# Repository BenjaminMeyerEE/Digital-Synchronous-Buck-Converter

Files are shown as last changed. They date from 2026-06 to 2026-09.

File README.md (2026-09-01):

# Digital Synchronous Buck Converter

12 V to 6 V, 10 A synchronous buck converter with closed-loop digital control on an
STM32G474RET6. Custom 4-layer board in KiCad. The firmware runs a 400 kHz PI voltage
loop with hardware-enforced dead-time and a comparator overcurrent trip that doesn't
depend on the CPU.

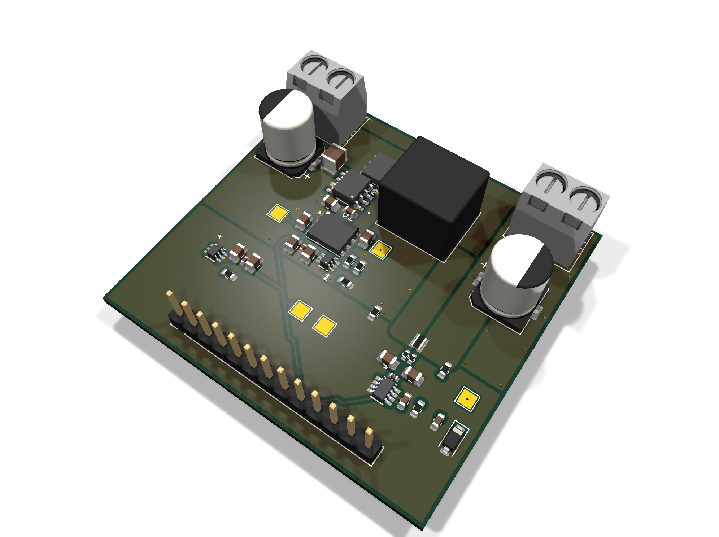
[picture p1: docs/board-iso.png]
Assembled board render


<!-- TODO
     - scope captures: switching node, gate drive dead-time, load step
     - characterization numbers, then update Status
     - write up why the F.Cu pour and In2.Cu are shaped the way they are
     images are all generated, see docs/regenerate-images.md
-->

## Specifications

| Parameter | Value |
|---|---|
| Input / output | 12 V → 6 V, 10 A |
| Board | 53.1 × 50.0 mm, 4-layer |
| Controller | STM32G474RET6 (Nucleo-G474RE) |
| Switching frequency | 400 kHz (TIM1 at 170 MHz, ARR = 424) |
| Control loop | Voltage-mode PI, one update per switching period (2.5 µs) |
| Dead-time | 100 ns, hardware-enforced (TIM1 DTG = 17) |
| Current sense | INA241A3, 50 V/V into a 5 mΩ shunt, so 0.25 V/A |
| Feedback divider | 0.4047619 (ADC sees V_out × gain) |
| Sampling | Dual-simultaneous 12-bit ADC, TIM1 TRGO triggered, DMA |
| Overcurrent protection | TLV3603 comparator into TIM1 BKIN2 |
| Gate driver | UCC27211D half-bridge |

## Status

The power stage works. I've driven it from a function generator and from the test
firmware in `test-firmware/`.

Still open: the main control firmware in `firmware/` hasn't run on hardware yet, so
the closed loop is unproven. The board also hasn't been characterized, so there are
no efficiency, regulation, ripple or thermal numbers. Both are waiting on lab
access, which was shut through August 2026.

## Repository layout

| Path | Contents |
|---|---|
| `hardware/` | KiCad 10 project: schematic, PCB, design rules, library tables |
| `firmware/` | Main control firmware (CubeMX + EWARM) |
| `test-firmware/` | Standalone open-loop PWM bring-up project |
| `fabrication/` | Gerbers, BOM, pick-and-place, interactive BOM |

## Hardware

4-layer stackup with a solid internal ground plane. All four copper layers are
plotted from the top and unmirrored so they line up with each other.

| `F.Cu` — top signal + power | `In1.Cu` — ground plane |
|---|---|
| F.Cu | In1.Cu |

| `In2.Cu` — power / signal | `B.Cu` — bottom signal + ground |
|---|---|
| In2.Cu | B.Cu |

`B.Cu` is meant to stay as close to unbroken ground as I could keep it. It only
carries routing where a connection couldn't be finished on another layer.

Schematic: [docs/schematic.pdf](docs/schematic.pdf). Top-down render:
[docs/board-top.png](docs/board-top.png).

27 BOM lines across 49 placements. Everything in `fabrication/` comes out of the
KiCad fabrication toolkit: gerbers, a JLCPCB-format BOM and centroid file, and an
interactive HTML BOM at `fabrication/bom/ibom.html`.

## Firmware

### Control

`Buck_CtrlLoopISR()` runs at 400 kHz. It's called from a lean direct-register DMA
handler rather than going through HAL dispatch, which keeps it inside the 2.5 µs
budget. V_FB and current sense are sampled at the same instant by the dual ADC and
come back as a single 32-bit DMA word.

PI with anti-windup. Integrator and duty are both clamped to `[0, duty_limit]`, and
the clamps reject NaN so a bad value written at runtime can't reach the duty cycle.
Analog scaling uses precomputed reciprocals to keep division out of the ISR.

Gains, setpoints and the overcurrent trip level are tunable at runtime over SWD with
STM32CubeMonitor. Monitoring variables are read-only.

### Protection

Overcurrent shutdown is pure hardware: the TLV3603 comparator drives TIM1 BKIN2
directly and kills the gates in under 100 ns. It still works with the CPU halted or
hung. The software break callback only does bookkeeping, forcing MOE off, masking
the break IRQ so it can't storm, and latching the fault.

IWDG is set to 2 s, and the main loop only refreshes it while the control ISR
heartbeat is advancing. A stalled ADC or DMA path resets the board to idle instead
of leaving the half-bridge running open-loop.

TIM3 dual-edge input capture timestamps the gate edges in hardware, so the
dead-time at the power stage is measured rather than assumed.

## Test firmware

`test-firmware/` is a separate project for bringing the power stage up before
closing the loop. Open-loop complementary PWM at 400 kHz with the same 100 ns
hardware dead-time. It holds everything off for 500 ms after reset so the rails
settle and the debugger can attach, then soft-starts by walking CCR up 4 counts
every 2 ms, roughly 106 ms from 0 to 50 % duty. Kept separate so the gate drive can
be checked on its own.

## Toolchain

The CubeMX project targets EWARM V8.50. It also builds clean under
`arm-none-eabi-gcc` 14.3 (the one bundled with STM32CubeIDE 2.1.1) at
`-O2 -Wall -Wextra` with no warnings, using about 64 KB of flash and 2.4 KB of RAM.

Flash over ST-Link with STM32CubeProgrammer. CubeMonitor needs the exact `.out` ELF
matching what's on the chip, otherwise the symbol addresses won't line up.

TIM1 and IWDG are both frozen on core halt via DBGMCU, so halting in the debugger is
safe. A halt does leave the gates frozen wherever they were. The BKIN2 kill still
works while halted, but don't halt under load with the OC comparator disarmed.

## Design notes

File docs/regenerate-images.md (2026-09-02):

# Regenerating the images

Everything in `docs/` is generated from the design files with `kicad-cli`, so the
images can be rebuilt after any board change rather than re-screenshotted.

On Windows the binary is at:

    "C:/Program Files/KiCad/10.0/bin/kicad-cli.exe"

Run all commands from the repository root.

## 3D renders

Isometric view (README header):

    kicad-cli pcb render -o docs/board-iso.png --quality high --perspective \
      --rotate '-30,0,-35' --zoom 0.7 --width 2000 --height 1500 \
      --background transparent hardware/synch_buck_digital.kicad_pcb

Top-down view:

    kicad-cli pcb render -o docs/board-top.png --side top --quality high \
      --width 2000 --height 1500 --background transparent \
      hardware/synch_buck_digital.kicad_pcb

Transparent backgrounds are deliberate — they read correctly on both GitHub's
light and dark themes.

## Copper layers

One SVG per copper layer, each with the board outline for reference:

    for pair in "F.Cu:layer-f-cu" "In1.Cu:layer-in1-cu" \
                "In2.Cu:layer-in2-cu" "B.Cu:layer-b-cu"; do
      L="${pair%%:*}"; N="${pair##*:}"
      kicad-cli pcb export svg -o "docs/$N.svg" --mode-single \
        --layers "$L,Edge.Cuts" --exclude-drawing-sheet --page-size-mode 2 \
        --check-zones hardware/synch_buck_digital.kicad_pcb
    done

Then darken the board outline, because KiCad plots `Edge.Cuts` as `#D0D2CD`,
which disappears against a white page:

    sed -i 's/#D0D2CD/#555555/g' docs/layer-*.svg

Two deliberate choices:

- **Silkscreen is excluded.** KiCad plots it as `#F2EDA1`, effectively invisible
  on GitHub's light background.
- **`B.Cu` is not mirrored.** Plotting every layer from the same side means
  features line up when comparing layers, which is the point of showing them.

## Schematic

    kicad-cli sch export pdf -o docs/schematic.pdf \
      hardware/synch_buck_digital.kicad_sch

## Notes

- `--check-zones` refills copper pours before plotting, so layer images always
  reflect the current zone settings.
- Close the KiCad PCB editor before regenerating. `kicad-cli` reads from disk,
  and an open editor can overwrite the board file when it saves.

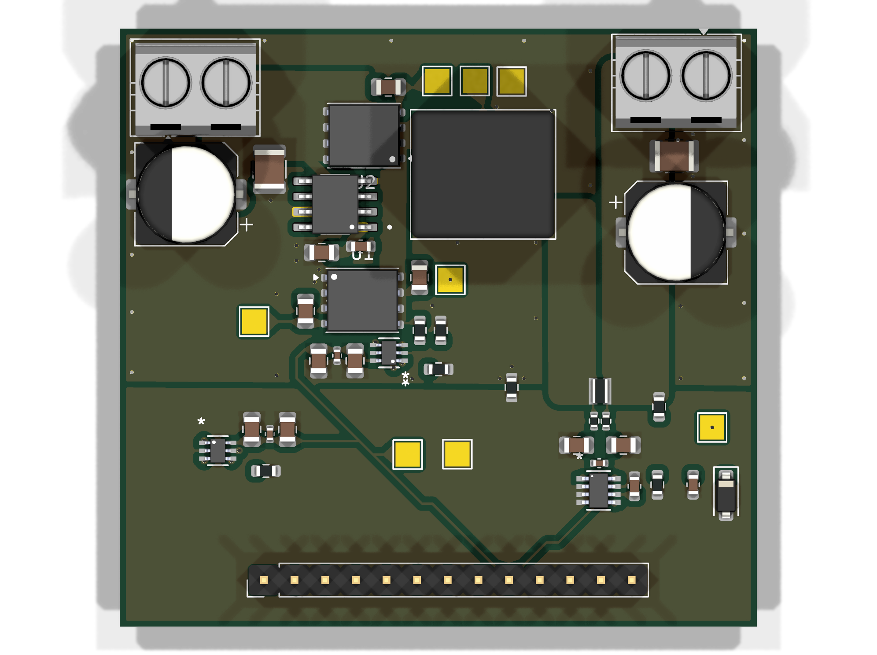
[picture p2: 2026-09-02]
docs/board-top.png

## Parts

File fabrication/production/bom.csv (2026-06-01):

Designator | Footprint | Quantity | Value | LCSC Part #
CB1 | 0805 | 1 | 47nF
C_DT_100P1, C_INA_FILT2, C_INA_FILT3, C_OC_100P1 | 0805 | 4 | 100pF
C_DT_10N1, C_OC_10N1 | 0402 | 2 | 10nF
C_DT_1U1, C_OC_1U1, C_UCC_VDD_HF1 | 0805 | 3 | 1uF
C_INA_FILT1 | 0402 | 1 | 1nF
C_INA_VCC1, C_UCC_VDD_LF1 | 0603 | 2 | 100nF
C_IN_HF1, C_OUT_HF1 | 1210 | 2 | 10uF
C_IN_LF1, C_OUT_LF1 | CP_Elec_8x10 | 2 | 47uF
C_VFB_FILT1 | 0603 | 1 | 1nF
D1 | D_SOD-123 | 1 | 3.3V
J_IN1, J_OUT1 | TerminalBlock_MaiXu_MX126-5.0-02P_1x02_P5.00mm | 2 | Conn_01x02
J_STM1 | PinHeader_1x13_P2.54mm_Vertical | 1 | Conn_01x13
L1 | L_Coilcraft_XAL1010-XXX | 1 | 6.8uH
R1 | 0603 | 1 | 0R
R1_DT1 | 0603 | 1 | 3.9KR
R1_VFB1 | 0603 | 1 | 6.8KR
R2_DT1 | 0603 | 1 | 1KR
R2_VFB1 | 0603 | 1 | 10KR
R_FILT_N1, R_FILT_P1 | 0402 | 2 | 10R
R_GATE_1, R_GATE_2 | 0805 | 2 | 10R
R_HYS1, R_HYS2 | 0603 | 2 | 75KR
R_SHUNT1 | RES_2012_SUS | 1 | 5mR
TP1, TP2, TP3, TP4, TP5, TP6, TP7, TP8 | TestPoint_Pad_2.0x2.0mm | 8 | TestPoint
U1, U2 | Infineon_PG-TDSON-8_6.15x5.15mm | 2 | BSC066N06NSATMA1
U3 | SOT23-8_DDF_TEX | 1 | INA241A3IDDFR
U_DT1, U_OC1 | SC70_DCK_TEX | 2 | TLV3603DCKR-ET
U_UCC1 | SOIC127P599X175-8N | 1 | UCC27211D

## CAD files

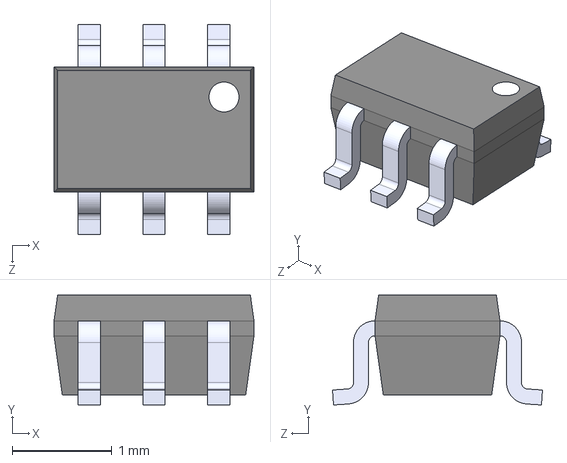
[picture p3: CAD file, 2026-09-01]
hardware/3dmodels/TLV3603DCKR.step
2.00 x 1.10 x 2.10 mm

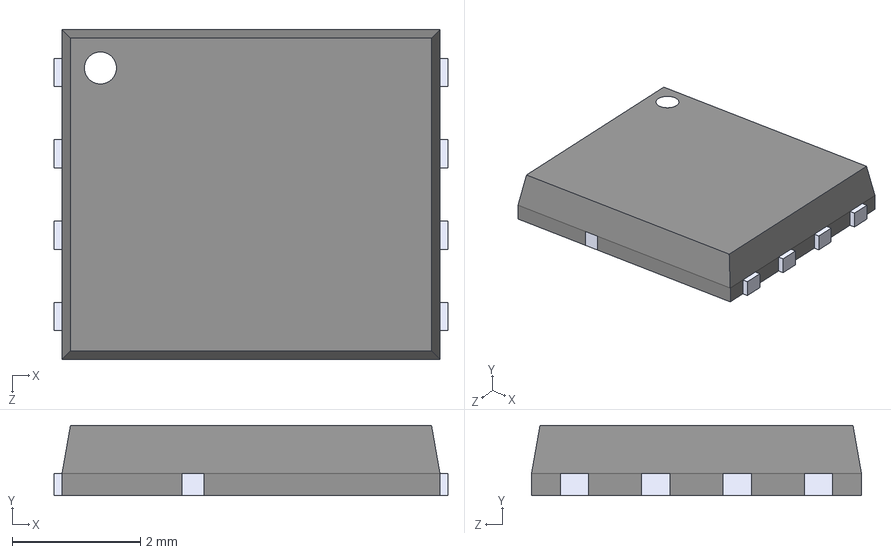
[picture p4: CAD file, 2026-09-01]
hardware/3dmodels/Infineon_PG-TDSON-8.step
6.15 x 1.10 x 5.15 mm

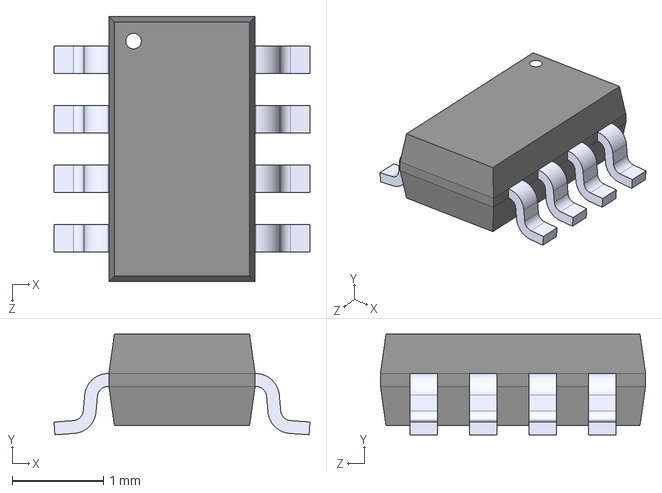
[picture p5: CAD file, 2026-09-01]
hardware/3dmodels/INA241A3IDDFR.step
2.80 x 1.10 x 2.90 mm

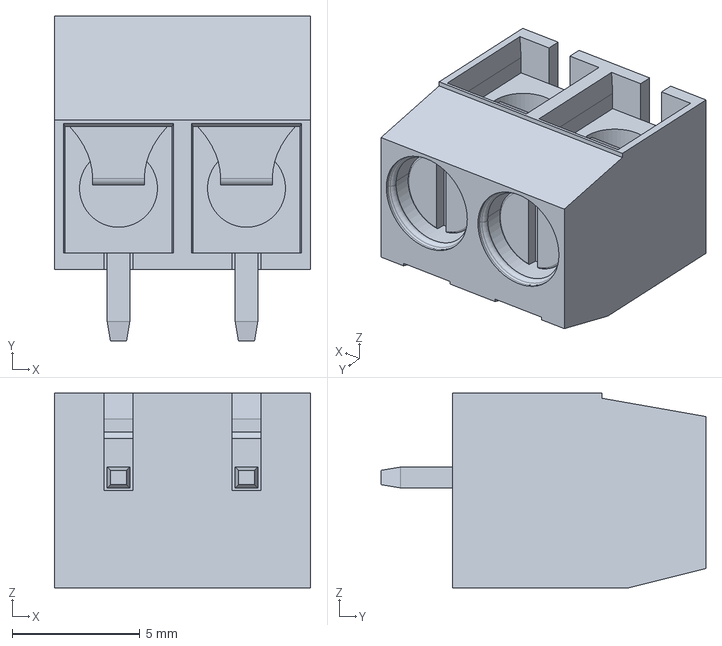
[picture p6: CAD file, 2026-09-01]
hardware/3dmodels/TerminalBlock_MX126-5.0-02P.step
10.0 x 12.7 x 7.62 mm

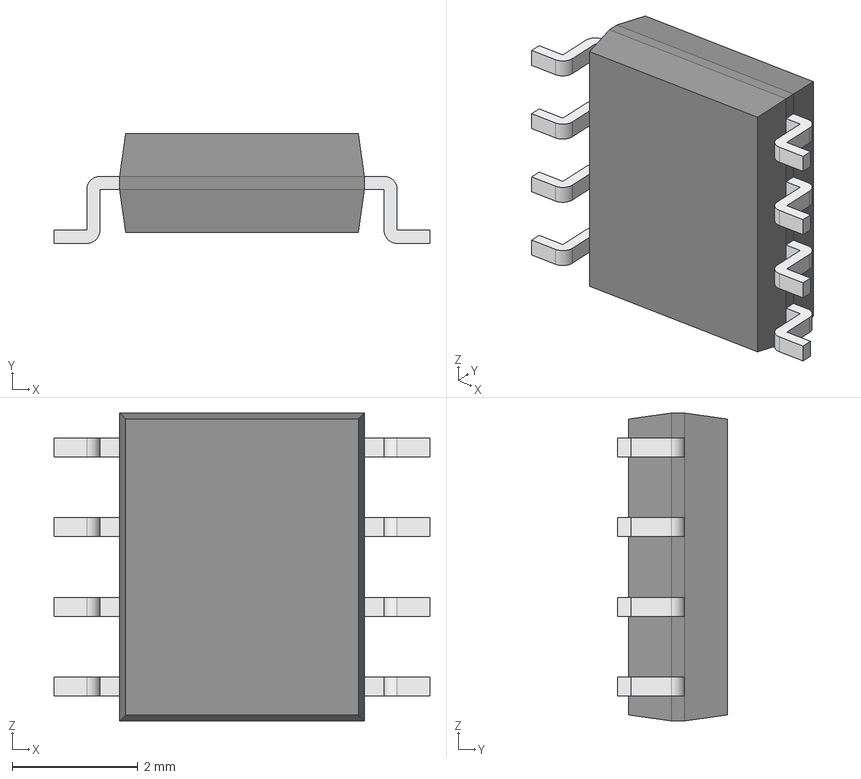
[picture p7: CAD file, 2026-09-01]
hardware/3dmodels/UCC27211D.step
5.99 x 1.75 x 4.91 mm
Body001 (Mirror #1) x 4
XY-plane x 12
X-axis x 12

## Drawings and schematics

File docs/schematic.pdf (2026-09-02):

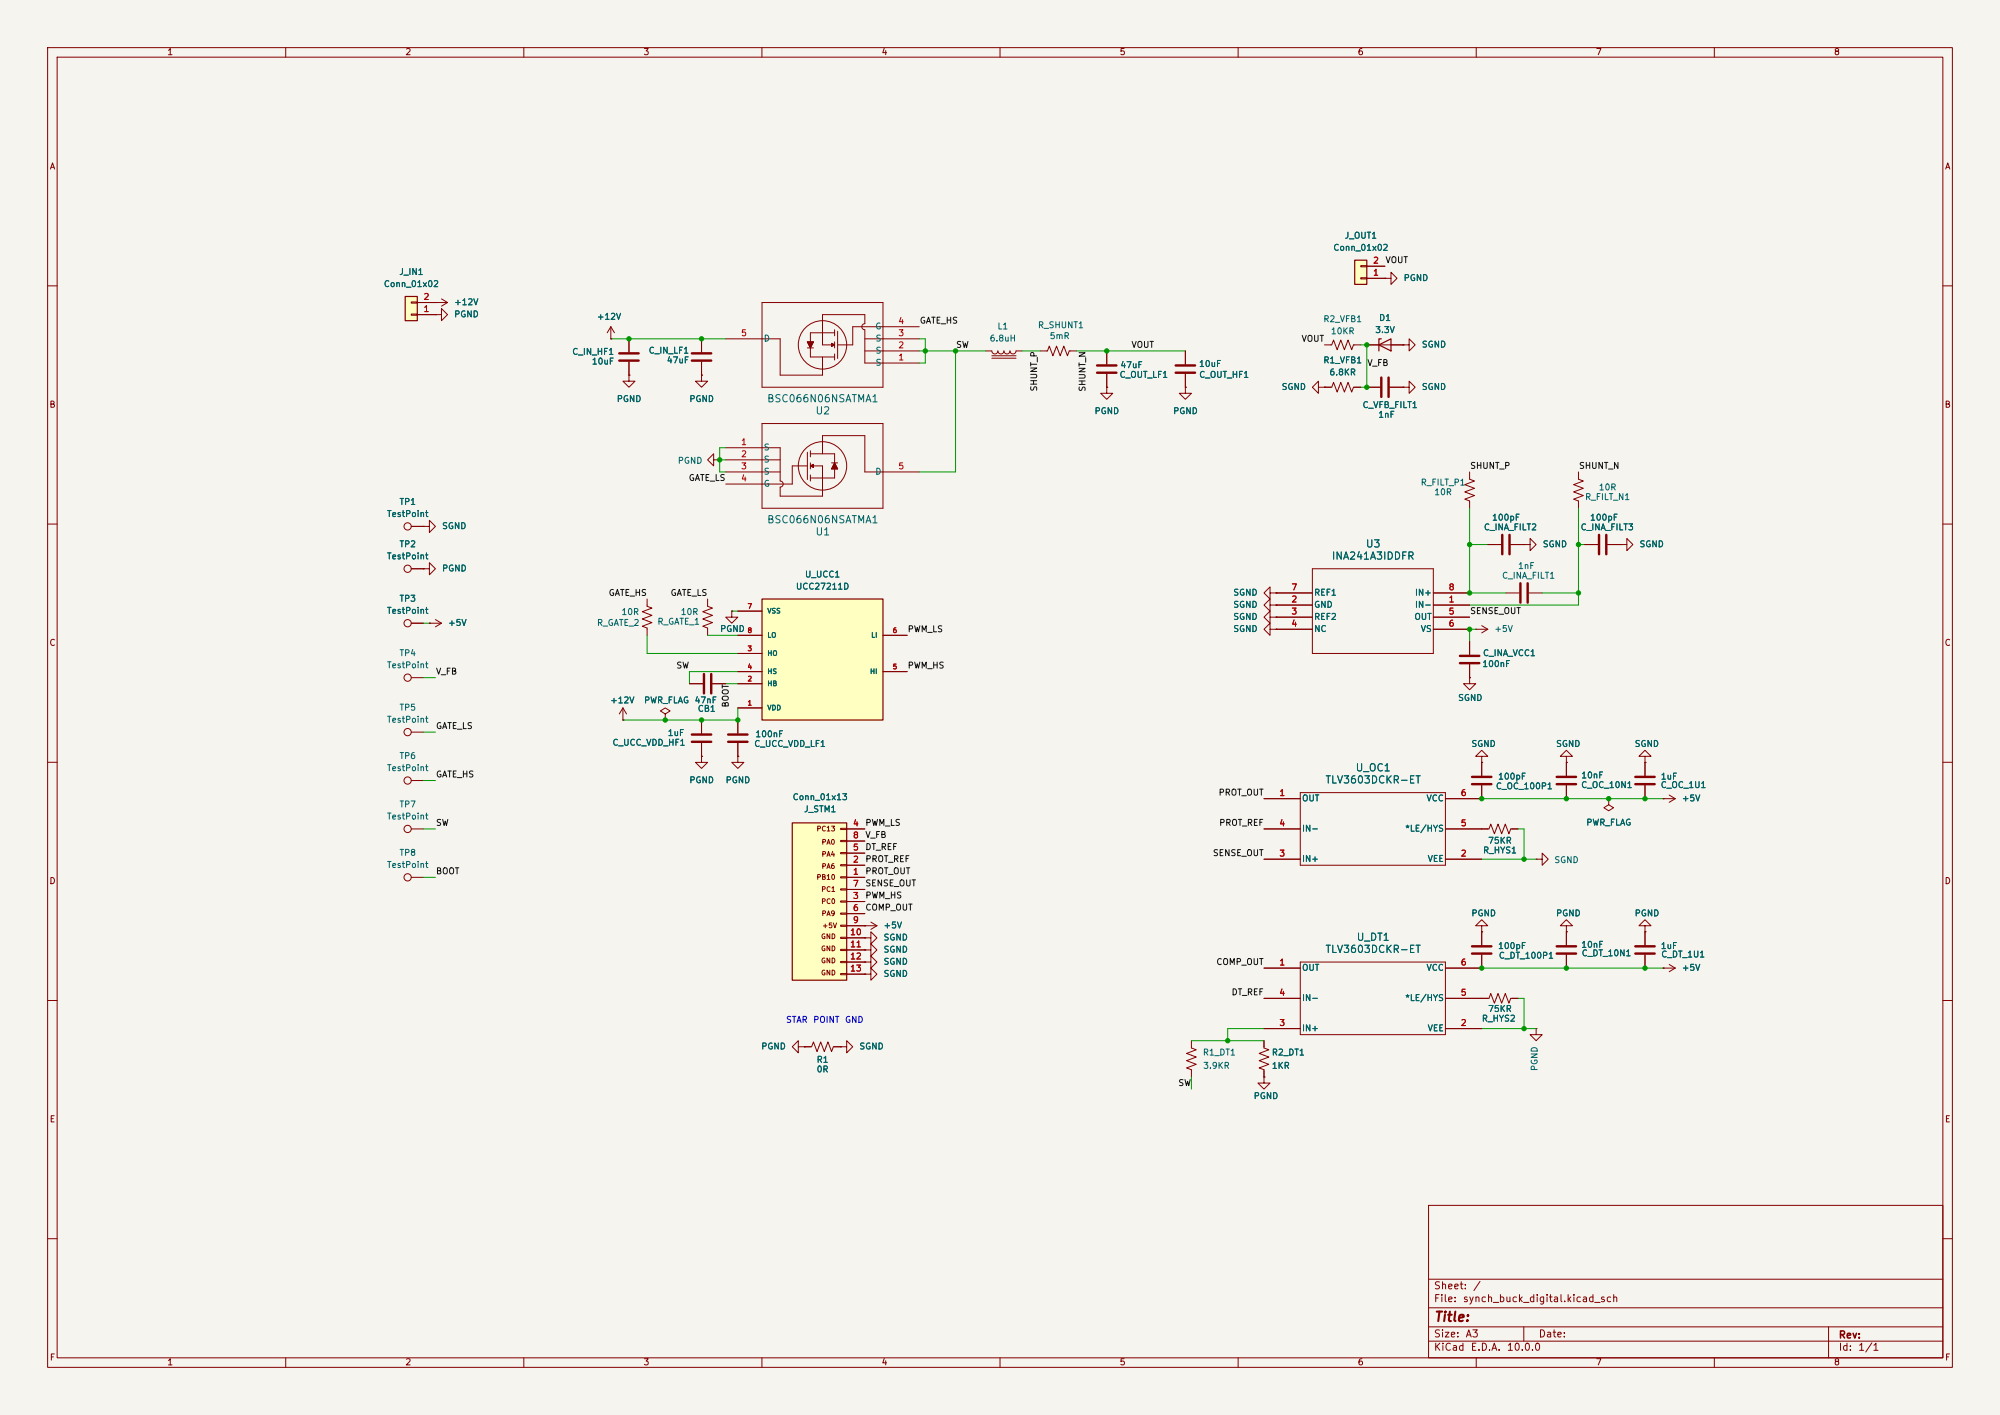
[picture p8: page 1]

Size: A3 | Rev: | F Date:
KiCad E.D.A. 10.0.0 | Id: 1/1

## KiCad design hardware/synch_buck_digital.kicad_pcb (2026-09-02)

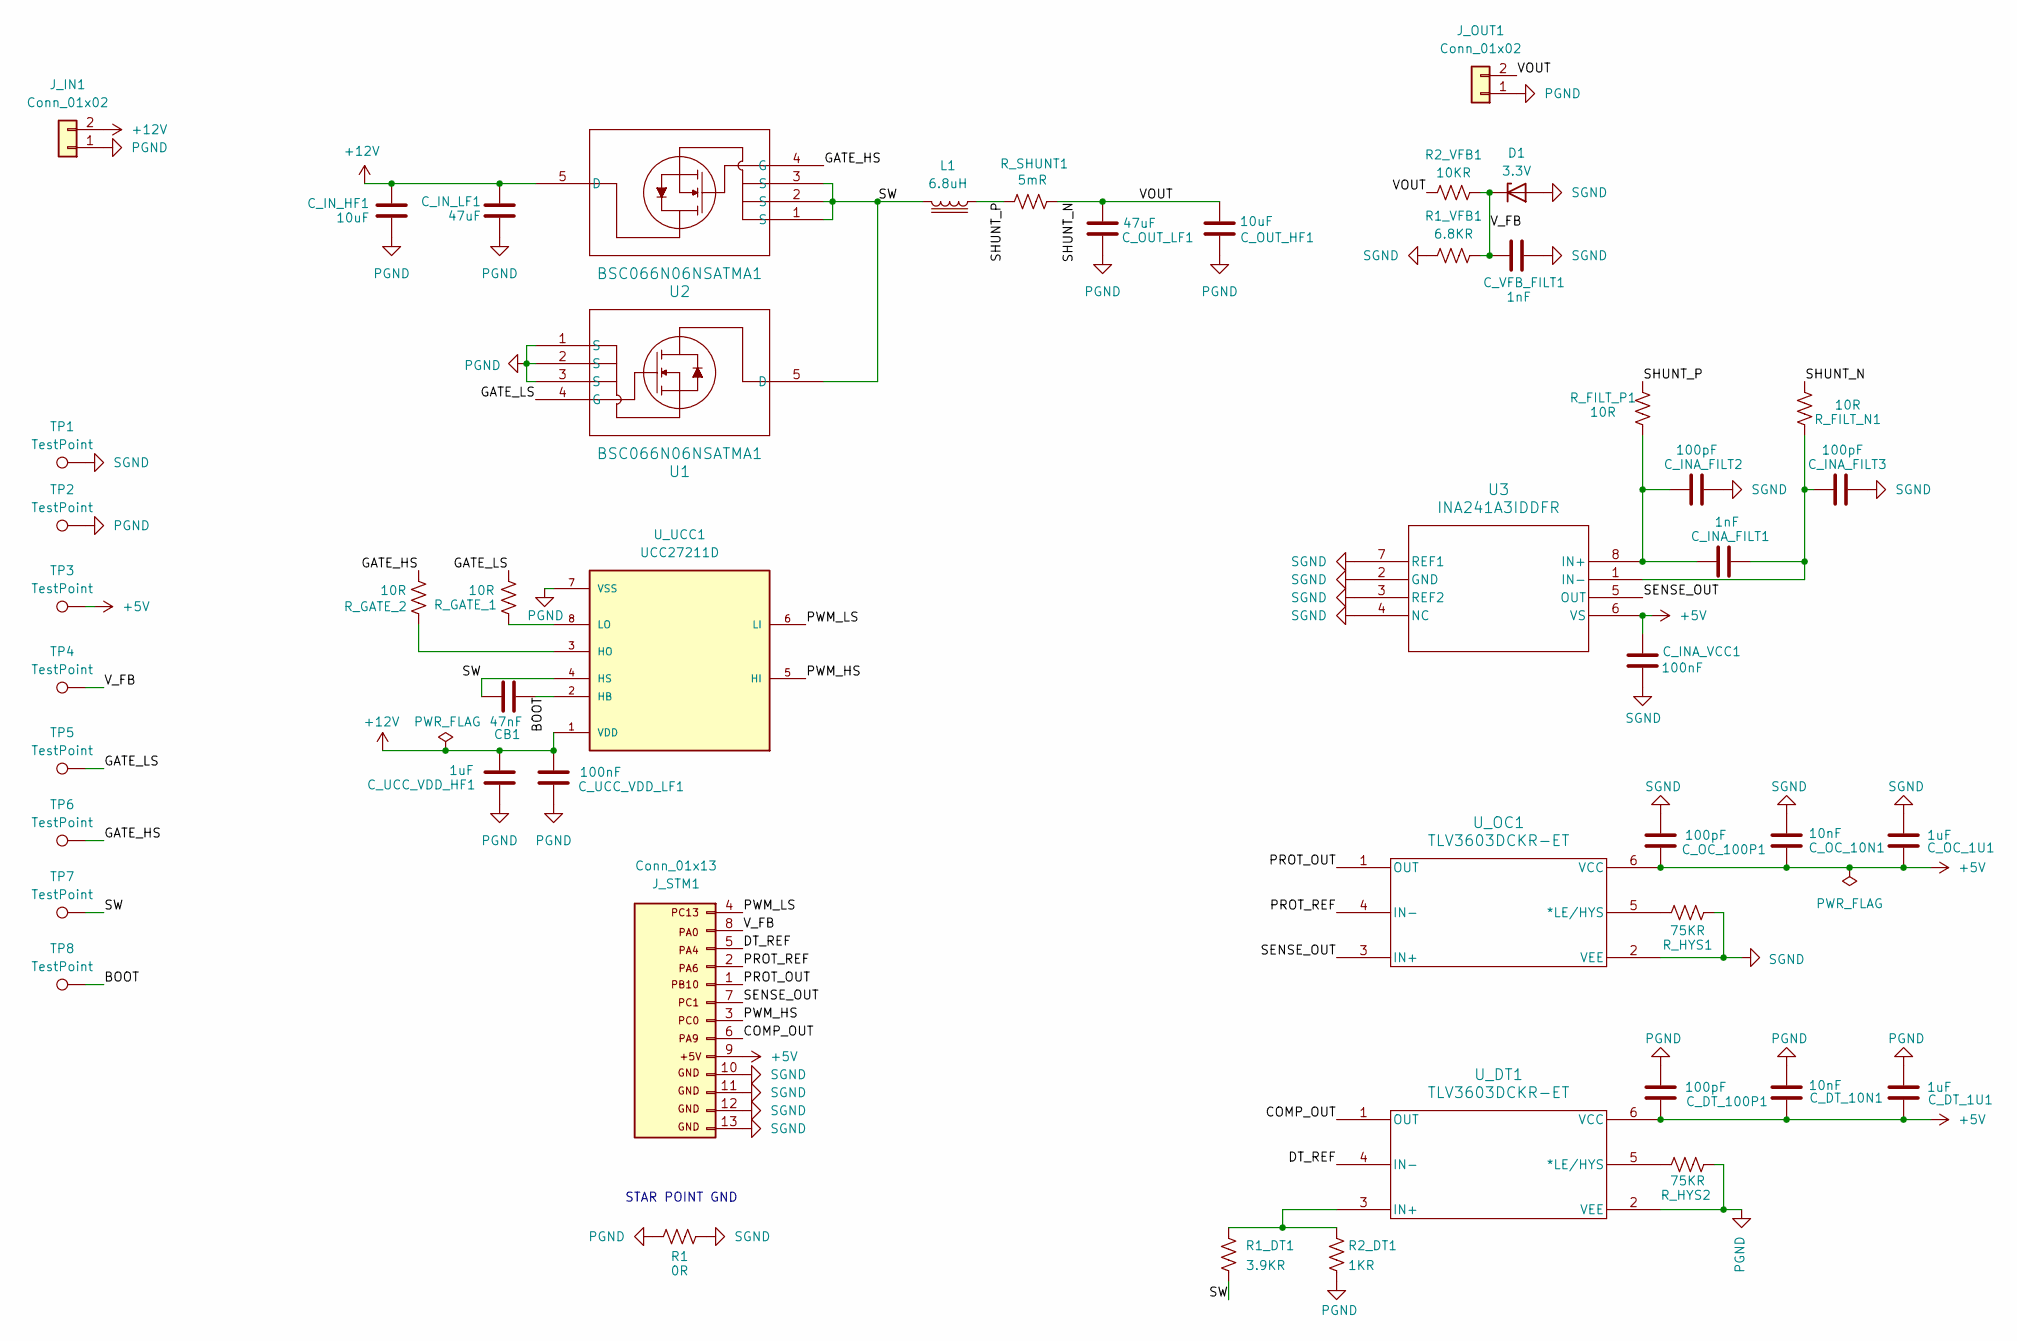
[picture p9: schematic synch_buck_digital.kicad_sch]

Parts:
CB1: 47nF; C_0805_2012Metric
C_DT_1U1: 1uF; C_0805_2012Metric
C_DT_10N1: 10nF; C_0402_1005Metric
C_DT_100P1: 100pF; C_0805_2012Metric
C_INA_FILT1: 1nF; C_0402_1005Metric
C_INA_FILT2, C_INA_FILT3: 100pF; C_0805_2012Metric
C_INA_VCC1: 100nF; C_0603_1608Metric
C_IN_HF1: 10uF; C_1210_3225Metric
C_IN_LF1: 47uF; CP_Elec_8x10
C_OC_1U1: 1uF; C_0805_2012Metric
C_OC_10N1: 10nF; C_0402_1005Metric
C_OC_100P1: 100pF; C_0805_2012Metric
C_OUT_HF1: 10uF; C_1210_3225Metric
C_OUT_LF1: 47uF; CP_Elec_8x10
C_UCC_VDD_HF1: 1uF; C_0805_2012Metric
C_UCC_VDD_LF1: 100nF; C_0603_1608Metric
C_VFB_FILT1: 1nF; C_0603_1608Metric
D1: 3.3V; D_SOD-123
J_IN1: Conn_01x02; TerminalBlock_MaiXu_MX126-5.0-02P_1x02_P5.00mm
J_OUT1: Conn_01x02; TerminalBlock_MaiXu_MX126-5.0-02P_1x02_P5.00mm
J_STM1: Conn_01x13; PinHeader_1x13_P2.54mm_Vertical
L1: 6.8uH; L_Coilcraft_XAL1010-XXX
R1: 0R
R1_DT1: 3.9KR; R_0603_1608Metric
R1_VFB1: 6.8KR; R_0603_1608Metric
R2_DT1: 1KR; R_0603_1608Metric
R2_VFB1: 10KR; R_0603_1608Metric
R_FILT_N1: 10R; R_0402_1005Metric
R_FILT_P1: 10R; R_0402_1005Metric
R_GATE_1, R_GATE_2: 10R; C_0805_2012Metric
R_HYS1, R_HYS2: 75KR; R_0603_1608Metric
R_SHUNT1: 5mR; RES_2012_SUS
TP1, TP2, TP3, TP4, TP5, TP6, TP7, TP8: TestPoint; TestPoint_Pad_2.0x2.0mm
U1, U2: BSC066N06NSATMA1; Infineon_PG-TDSON-8_6.15x5.15mm
U3: INA241A3IDDFR; SOT23-8_DDF_TEX
U_DT1: TLV3603DCKR-ET; SC70_DCK_TEX
U_OC1: TLV3603DCKR-ET; SC70_DCK_TEX
U_UCC1: UCC27211D; SOIC127P599X175-8N; PARTREV F

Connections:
+5V: C_DT_1U1.1, C_DT_10N1.1, C_DT_100P1.1, C_INA_VCC1.1, C_OC_1U1.1, C_OC_10N1.1, C_OC_100P1.1, J_STM1.9, TP3.1 (1_1), U3.6 (VS), U_DT1.6 (VCC), U_OC1.6 (VCC)
+12V: C_IN_HF1.1, C_IN_LF1.1, C_UCC_VDD_HF1.2, C_UCC_VDD_LF1.2, J_IN1.2, U2.5 (D), U_UCC1.1 (VDD)
/BOOT: CB1.1, TP8.1 (1_1), U_UCC1.2 (HB)
/COMP_OUT: J_STM1.6 (Pin_8), U_DT1.1 (OUT)
/DT_REF: J_STM1.5 (Pin_3), U_DT1.4 (IN-)
/GATE_HS: R_GATE_2.1, TP6.1 (1_1), U2.4 (G)
/GATE_LS: R_GATE_1.2, TP5.1 (1_1), U1.4 (G)
/PROT_OUT: J_STM1.1 (Pin_5), U_OC1.1 (OUT)
/PROT_REF: J_STM1.2 (Pin_4), U_OC1.4 (IN-)
/PWM_HS: J_STM1.3 (Pin_7), U_UCC1.5 (HI)
/PWM_LS: J_STM1.4 (Pin_1), U_UCC1.6 (LI)
/SENSE_OUT: J_STM1.7 (Pin_6), U3.5 (OUT), U_OC1.3 (IN+)
/SHUNT_N: C_OUT_HF1.1, C_OUT_LF1.1, J_OUT1.2, R2_VFB1.1, R_FILT_N1.2, R_SHUNT1.2
/SHUNT_P: L1.1, R_FILT_P1.1, R_SHUNT1.1
/SW: CB1.2, L1.2, R1_DT1.2, TP7.1 (1_1), U1.5 (D), U2.1 (S), U2.2 (S), U2.3 (S), U_UCC1.4 (HS)
/V_FB: C_VFB_FILT1.2, D1.1 (K), J_STM1.8 (Pin_2), R1_VFB1.2, R2_VFB1.2, TP4.1 (1_1)
unnamed: C_INA_FILT1.2, C_INA_FILT2.2, R_FILT_P1.2, U3.8 (IN+)
unnamed: C_INA_FILT1.1, C_INA_FILT3.2, R_FILT_N1.1, U3.1 (IN-)
unnamed: R_HYS2.2, U_DT1.5 (*LE/HYS)
unnamed: R1_DT1.1, R2_DT1.2, U_DT1.3 (IN+)
unnamed: R_HYS1.2, U_OC1.5 (*LE/HYS)
unnamed: R_GATE_2.2, U_UCC1.3 (HO)
unnamed: R_GATE_1.1, U_UCC1.8 (LO)
PGND: C_DT_1U1.2, C_DT_10N1.2, C_DT_100P1.2, C_IN_HF1.2, C_IN_LF1.2, C_OUT_HF1.2, C_OUT_LF1.2, C_UCC_VDD_HF1.1, C_UCC_VDD_LF1.1, J_IN1.1, J_OUT1.1, R1.1, R2_DT1.1, R_HYS2.1, TP2.1 (1_1), U1.1 (S), U1.2 (S), U1.3 (S), U_DT1.2 (VEE), U_UCC1.7 (VSS)
SGND: C_INA_FILT2.1, C_INA_FILT3.1, C_INA_VCC1.2, C_OC_1U1.2, C_OC_10N1.2, C_OC_100P1.2, C_VFB_FILT1.1, D1.2 (A), J_STM1.10, J_STM1.11, J_STM1.12, J_STM1.13, R1.2, R1_VFB1.1, R_HYS1.1, TP1.1 (1_1), U3.2 (GND), U3.3 (REF2), U3.4 (NC), U3.7 (REF1), U_OC1.2 (VEE)

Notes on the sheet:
STAR POINT GND

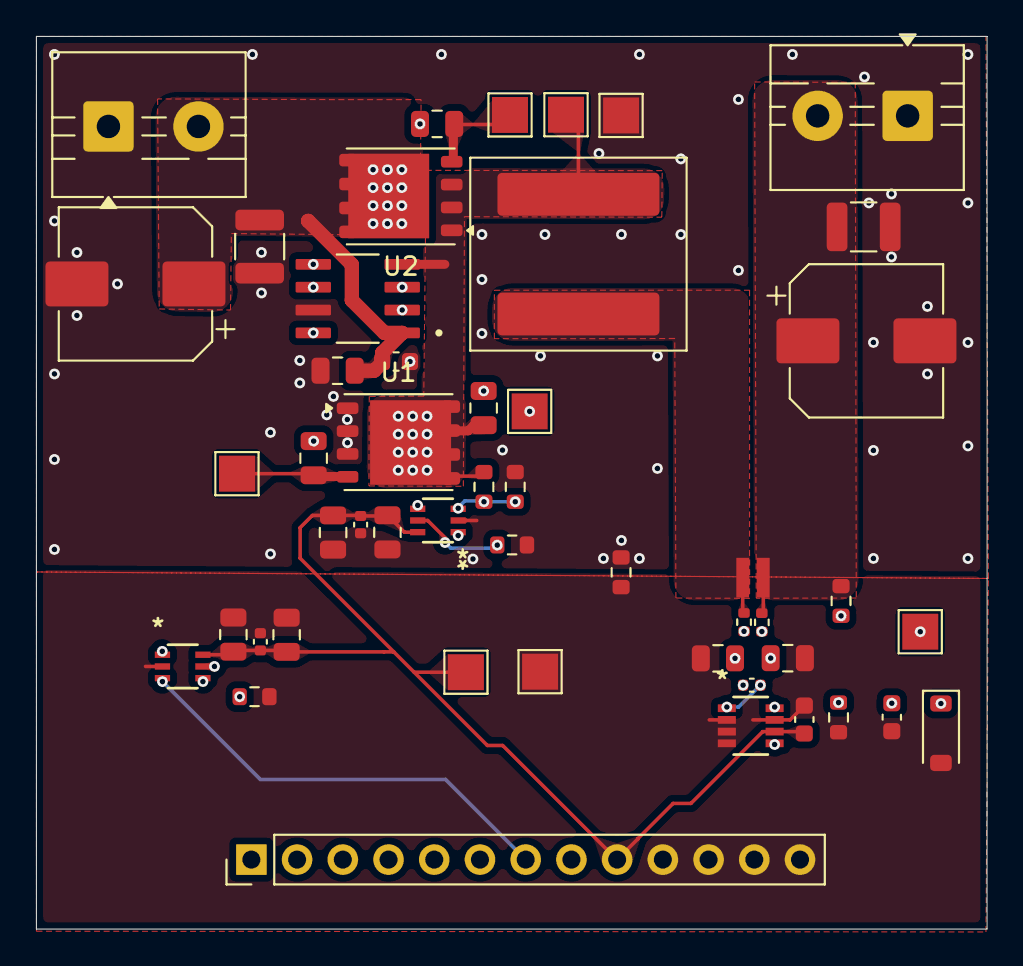
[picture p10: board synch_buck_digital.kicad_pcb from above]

Board: 4 copper layers, 52.8 x 49.6 mm, 49 parts (0 on the bottom side), 25 nets.

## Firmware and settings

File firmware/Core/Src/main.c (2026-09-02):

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
/* Includes ------------------------------------------------------------------*/
#include "main.h"

/* USER CODE BEGIN PTD */
/* sys_state_t moved to main.h (USER CODE ET): it is now shared with the lean
 * DMA error path in stm32g4xx_it.c, which latches SYS_STATE_FAULT directly. */
/* USER CODE END PTD */

/* USER CODE BEGIN PD */
/* --- Power stage / timing --------------------------------------------------
 * TIM1: 170 MHz, PSC = 0, ARR = 424 -> Fsw = 400 kHz, period = 2.5 us.
 * DTG = 17 -> hardware dead-time = 17 / 170 MHz = 100 ns per switching edge. */
#define PWM_PERIOD_TICKS        425.0f      /* ARR + 1                                    */
#define CTRL_TS_SEC             2.5e-6f     /* control ISR period (TIM1 update = 400 kHz) */
#define PWM_DEADTIME_NS         100.0f
#define PWM_PERIOD_NS           2500.0f
/* LS on-time loses one dead-time at each of its two transitions -> 8 % of period */
#define PWM_DEADTIME_PCT        (2.0f * PWM_DEADTIME_NS / PWM_PERIOD_NS * 100.0f)
#define CCR_TO_PCT              (100.0f / PWM_PERIOD_TICKS)

/* --- Analog scaling (precomputed reciprocals: no division in the ISR) ------ */
#define ADC_VREF_V              3.3f
#define ADC_FULL_SCALE          4095.0f
#define VFB_DIVIDER_GAIN        0.4047619f  /* V_FB divider: ADC sees Vout * this         */
#define CURR_SENSE_V_PER_A      0.25f       /* INA241A3 gain 50 x 5 mOhm shunt            */
#define ADC_RAW_TO_VOUT_V       ((ADC_VREF_V / ADC_FULL_SCALE) / VFB_DIVIDER_GAIN)   /* ~1.9910e-3 V/LSB */
#define ADC_RAW_TO_AMPS         ((ADC_VREF_V / ADC_FULL_SCALE) / CURR_SENSE_V_PER_A) /* ~3.2234e-3 A/LSB */
#define AMPS_TO_DAC_COUNTS      (CURR_SENSE_V_PER_A * ADC_FULL_SCALE / ADC_VREF_V)   /* ~310.23 LSB/A    */
#define DAC_FULL_SCALE_A        13.2f       /* 3.3 V / 0.25 V/A: max representable trip   */

/* --- Limits / interlocks ---------------------------------------------------- */
#define OC_TRIP_MIN_A           0.5f        /* start refused while set_oc_trip_A < this   */
#define DUTY_MAX_ABS            0.98f       /* absolute ceiling for set_duty_max          */
#define VOUT_SET_MAX_V          8.0f        /* V_FB divider saturates the ADC at ~8.15 V  */
#define SOFTSTART_MS_MIN        1.0f        /* also guards the ramp-increment division    */
#define SOFTSTART_MS_MAX        10000.0f

/* --- Start-up hold ----------------------------------------------------------
 * Nothing may be armed for this long after reset. Gives the input rail, the
 * INA241 sense amp and the TLV3603 OC comparator (whose PROT_REF is only
 * written once the main loop reaches app_apply_dac_refs()) time to settle, and
 * gives the debugger time to take hold before the half-bridge can ever be
 * energized. Enforced as a non-blocking gate on cmd_start rather than as a
 * HAL_Delay(): the main loop must keep servicing the IWDG heartbeat gate and
 * the CubeMonitor variables throughout the hold.                              */
#define STARTUP_HOLD_MS         500u

/* --- LD2 state indicator blink cadence (non-blocking) ----------------------- */
#define LED_BLINK_SOFTSTART_MS  100u        /* fast blink while ramping                  */
#define LED_BLINK_RUN_MS        500u        /* slow blink while regulating               */
/* USER CODE END PD */


COM_InitTypeDef BspCOMInit;
ADC_HandleTypeDef hadc1;
ADC_HandleTypeDef hadc2;
DMA_HandleTypeDef hdma_adc1;

DAC_HandleTypeDef hdac1;
DAC_HandleTypeDef hdac2;

IWDG_HandleTypeDef hiwdg;

TIM_HandleTypeDef htim1;
TIM_HandleTypeDef htim3;

/* USER CODE BEGIN PV */
/* ===================== CubeMonitor: monitoring (firmware -> user) ========= */
volatile float    mon_vout_V             = 0.0f;           /* measured output voltage [V]            */
volatile float    mon_current_A          = 0.0f;           /* measured output current [A]            */
volatile float    mon_pwm_hs_duty_pct    = 0.0f;           /* high-side effective duty [%]           */
volatile float    mon_pwm_ls_duty_pct    = 0.0f;           /* low-side effective duty [%]            */
volatile uint8_t  mon_pwm_hs_active      = 0u;             /* 1 = MOE on and HS switching            */
volatile uint8_t  mon_pwm_ls_active      = 0u;             /* 1 = MOE on (LS driven)                 */
volatile uint8_t  mon_prot_out_state     = 0u;             /* live PROT_OUT pin level (PA11)         */
volatile uint8_t  mon_dt_out_state       = 0u;             /* live DT_OUT comparator level (PB4)     */
volatile uint32_t mon_dt_edge_count      = 0u;             /* total DT_OUT edges captured by TIM3    */
volatile uint32_t mon_dt_pulse_width_ns  = 0u;             /* last DT_OUT high-pulse width [ns]      */
volatile uint8_t  mon_sys_state          = SYS_STATE_INIT; /* sys_state_t enum                       */
volatile uint8_t  mon_fault_latched      = 0u;             /* 1 = BRK2 fault latched                 */
volatile uint8_t  mon_interlock_oc_not_armed = 0u;         /* 1 = set_oc_trip_A < 0.5 A, start blocked */
volatile uint32_t mon_ctrl_loop_count    = 0u;             /* 400 kHz control ISR heartbeat          */

/* ===================== CubeMonitor: tunables (user -> firmware) =========== */
volatile float set_vout_V       = 6.0f;   /* output voltage setpoint [V], clamp [0, 8.0]             */
volatile float set_kp           = 0.02f;  /* PI proportional gain [duty/V], clamp >= 0               */
volatile float set_ki           = 50.0f;  /* PI integral gain [duty/(V*s)], clamp >= 0               */
volatile float set_oc_trip_A    = 0.0f;   /* OC comparator trip [A]; must be >= 0.5 A to allow start */
volatile float set_dt_ref_A     = 0.1f;   /* switching-activity comparator threshold [A]             */
volatile float set_duty_max     = 0.95f;  /* HS duty ceiling [0..1], clamp [0, 0.98]                 */
volatile float set_softstart_ms = 50.0f;  /* soft-start ramp duration [ms], clamp [1, 10000]         */

/* ===================== CubeMonitor: commands (write 1; consumed by main loop) */
volatile uint8_t cmd_start       = 0u;    /* request IDLE -> SOFT_START                              */
volatile uint8_t cmd_stop        = 0u;    /* request SOFT_START/RUN -> IDLE                          */
volatile uint8_t cmd_clear_fault = 0u;    /* request FAULT -> IDLE (only if PROT_OUT low)            */

/* ===================== internal control state ============================= */
static volatile uint32_t adc_dual_raw = 0u;       /* DMA dest: ADC1 (V_FB) low half, ADC2 (SENSE) high half */
static volatile float ctrl_integrator = 0.0f;     /* PI integrator [duty]                                   */
static volatile float ctrl_duty_limit = 0.0f;     /* soft-start ramped duty ceiling [duty]                  */
static volatile float ctrl_ss_increment = 0.0f;   /* duty-limit increment per control tick                  */
static volatile float ctrl_duty_max_cached = 0.0f;/* clamped copy of set_duty_max (main-loop owned)         */
static volatile uint8_t ctrl_ramp_done = 0u;      /* control ISR -> main loop: soft-start ramp finished     */
static float dac_oc_applied_A = -1.0f;            /* last value written to PROT_REF (-1 forces first write) */
static float dac_dt_applied_A = -1.0f;            /* last value written to DT_REF                           */
static uint32_t iwdg_last_ctrl_count = 0u;        /* main-loop copy of the control heartbeat                */
static uint32_t led_last_toggle_ms = 0u;          /* HAL_GetTick() at the last LD2 toggle (blink codes)     */
/* USER CODE END PV */

void SystemClock_Config(void);
static void MX_GPIO_Init(void);
static void MX_DMA_Init(void);
static void MX_ADC1_Init(void);
static void MX_ADC2_Init(void);
static void MX_TIM1_Init(void);
static void MX_DAC1_Init(void);
static void MX_DAC2_Init(void);
static void MX_IWDG_Init(void);
static void MX_TIM3_Init(void);
/* USER CODE BEGIN PFP */
static void app_clamp_tunables(void);
static void app_apply_dac_refs(void);
static void app_enter_idle(void);
static void app_arm_soft_start(void);
static void app_clear_fault(void);
/* USER CODE END PFP */

/**
  * @brief  The application entry point.
  * @retval int
  */
int main(void)
{

  /* MCU Configuration--------------------------------------------------------*/

  /* Reset of all peripherals, Initializes the Flash interface and the Systick. */
  HAL_Init();

  /* Configure the system clock */
  SystemClock_Config();

  /* USER CODE BEGIN SysInit */
  /* Freeze TIM1 and IWDG while the core is halted by the debugger: breakpoints
     must not leave the power stage mid-PWM-cycle or trip the watchdog.        */
  __HAL_DBGMCU_FREEZE_TIM1();
  __HAL_DBGMCU_FREEZE_IWDG();
  /* USER CODE END SysInit */

  /* Initialize all configured peripherals */
  MX_GPIO_Init();
  MX_DMA_Init();
  MX_ADC1_Init();
  MX_ADC2_Init();
  MX_TIM1_Init();
  MX_DAC1_Init();
  MX_DAC2_Init();
  MX_IWDG_Init();
  MX_TIM3_Init();
  /* USER CODE BEGIN 2 */
  /* --- ADC calibration: both units, single-ended, before any conversion --- */
  if (HAL_ADCEx_Calibration_Start(&hadc1, ADC_SINGLE_ENDED) != HAL_OK)
  {
    Error_Handler();
  }
  if (HAL_ADCEx_Calibration_Start(&hadc2, ADC_SINGLE_ENDED) != HAL_OK)
  {
    Error_Handler();
  }

  /* --- DAC comparator references: start and apply the power-on defaults.
         PROT_REF (DAC1_OUT1/PA4) from set_oc_trip_A (default 0 A = disarmed),
         DT_REF   (DAC2_OUT1/PA6) from set_dt_ref_A  (default 0.1 A).        */
  if (HAL_DAC_Start(&hdac1, DAC_CHANNEL_1) != HAL_OK)
  {
    Error_Handler();
  }
  if (HAL_DAC_Start(&hdac2, DAC_CHANNEL_1) != HAL_OK)
  {
    Error_Handler();
  }
  app_clamp_tunables();
  app_apply_dac_refs();

  /* --- Dual regular-simultaneous ADC via DMA: one circular 32-bit transfer
         from the common data register (ADC1 low half, ADC2 high half).      */
  if (HAL_ADCEx_MultiModeStart_DMA(&hadc1, (uint32_t *)&adc_dual_raw, 1u) != HAL_OK)
  {
    Error_Handler();
  }
  /* With NDTR = 1 the half-transfer event fires together with transfer-complete;
     left enabled it would double the 400 kHz interrupt load for nothing. Only
     TC runs the lean dispatch in DMA1_Channel1_IRQHandler (stm32g4xx_it.c),
     which clears the stale HT flag alongside TC.                              */
  __HAL_DMA_DISABLE_IT(&hdma_adc1, DMA_IT_HT);

  /* --- TIM3 input captures for the switching-activity comparator (DT_OUT/PB4).
         Edges are serviced by a lean handler in stm32g4xx_it.c.              */
  if (HAL_TIM_IC_Start_IT(&htim3, TIM_CHANNEL_1) != HAL_OK)  /* rising edge  */
  {
    Error_Handler();
  }
  if (HAL_TIM_IC_Start_IT(&htim3, TIM_CHANNEL_2) != HAL_OK)  /* falling edge */
  {
    Error_Handler();
  }

  /* --- TIM1: run the counter so TRGO keeps triggering the ADCs from boot, with
         both gate outputs held inactive. HAL_TIM_PWM_Start/PWMN_Start are NOT
         used here: both set MOE internally, which would drive the LS gate for
         several microseconds at boot — dangerous after a warm reset with a
         charged output. Direct register writes enable the channels and the
         counter without ever touching MOE (CCR1 is already 0, MOE stays 0 from
         reset); OSSR = Enable means both outputs are actively driven to their
         inactive level, not floated. app_arm_soft_start() is the ONLY place in
         the firmware where MOE is ever set.                                   */
  htim1.Instance->CCR1 = 0u;
  TIM1->CCER |= (TIM_CCER_CC1E | TIM_CCER_CC1NE);  /* HS: PA8, LS: PA7        */
  TIM1->CR1  |= TIM_CR1_CEN;                       /* TRGO = Update -> ADCs   */
  /* The generated init does not enable the break interrupt source; the NVIC
     vector alone is not enough for HAL_TIMEx_Break2Callback to fire.         */
  __HAL_TIM_ENABLE_IT(&htim1, TIM_IT_BREAK);

  /* INIT -> IDLE: outputs off, converter waits for cmd_start. A BRK2 event can
     already fire here (PROT_OUT stuck high at boot) — never overwrite a
     freshly latched FAULT with IDLE.                                          */
  __disable_irq();
  if (mon_sys_state != SYS_STATE_FAULT)
  {
    mon_sys_state = SYS_STATE_IDLE;
  }
  __enable_irq();
  /* USER CODE END 2 */

  /* Initialize led */
  BSP_LED_Init(LED_GREEN);

  /* Initialize COM1 port (115200, 8 bits (7-bit data + 1 stop bit), no parity */
  BspCOMInit.BaudRate   = 115200;
  BspCOMInit.WordLength = COM_WORDLENGTH_8B;
  BspCOMInit.StopBits   = COM_STOPBITS_1;
  BspCOMInit.Parity     = COM_PARITY_NONE;
  BspCOMInit.HwFlowCtl  = COM_HWCONTROL_NONE;
  if (BSP_COM_Init(COM1, &BspCOMInit) != BSP_ERROR_NONE)
  {
    Error_Handler();
  }

  /* Infinite loop */
  /* USER CODE BEGIN WHILE */
  while (1)
  {
    /* --- live pin monitors (GPIO input path is valid even in AF mode) ------ */
    mon_prot_out_state = (uint8_t)((GPIOA->IDR >> 11) & 1u); /* PA11 = PROT_OUT / TIM1_BKIN2 */
    mon_dt_out_state   = (uint8_t)((GPIOB->IDR >> 4) & 1u);  /* PB4  = DT_OUT (this poll is the single owner) */

    /* --- tunable sanitation + DAC reference updates ------------------------ */
    app_clamp_tunables();
    app_apply_dac_refs();

    /* live interlock indicator: start refused while the OC trip is below minimum.
       Single volatile read, NaN-rejecting comparison: a NaN written between the
       clamp above and this line must read as "not armed".                      */
    {
      float oc_trip = set_oc_trip_A;
      mon_interlock_oc_not_armed = (!(oc_trip >= OC_TRIP_MIN_A)) ? 1u : 0u;
    }

    /* --- consume commands / state machine ---------------------------------- */
    if (cmd_stop != 0u)
    {
      cmd_stop = 0u;
      if ((mon_sys_state == SYS_STATE_SOFT_START) || (mon_sys_state == SYS_STATE_RUN))
      {
        app_enter_idle();
      }
    }

    if (cmd_start != 0u)
    {
      /* Start-up hold: refuse to arm until STARTUP_HOLD_MS has elapsed since
         reset (see STARTUP_HOLD_MS). The command is deliberately NOT consumed
         inside the hold, so a start requested early — e.g. a CubeMonitor write
         landing right after an IWDG-driven reset — is honoured the moment the
         hold expires instead of being silently dropped.                       */
      if (HAL_GetTick() >= STARTUP_HOLD_MS)
      {
        cmd_start = 0u;
        if ((mon_sys_state == SYS_STATE_IDLE) && (mon_interlock_oc_not_armed == 0u))
        {
          app_arm_soft_start();
        }
      }
    }

    if (cmd_clear_fault != 0u)
    {
      cmd_clear_fault = 0u;
      /* explicit FAULT -> IDLE transition; refuses (atomically, on the live
         PA11 level) while the OC comparator output is still tripped (high)   */
      app_clear_fault();
    }

    /* --- SOFT_START -> RUN: performed here, not in the control ISR, so the
           state machine has a single ISR writer (the break path) and the
           transition can never depend on interrupt priorities.               */
    if (ctrl_ramp_done != 0u)
    {
      __disable_irq();
      if (mon_sys_state == SYS_STATE_SOFT_START)
      {
        mon_sys_state = SYS_STATE_RUN;
      }
      ctrl_ramp_done = 0u;
      __enable_irq();
    }

    /* --- LD2 state indicator ------------------------------------------------
           The converter is driven from CubeMonitor, but the bench operator
           still needs glance-able state with no debugger attached — the same
           blink-code idea the open-loop bring-up firmware uses. Done off
           HAL_GetTick() rather than HAL_Delay(): blocking here would stall the
           command handling and the IWDG heartbeat gate below.
             solid on   = FAULT (latched)
             fast blink = SOFT_START (duty limit ramping)
             slow blink = RUN (closed-loop regulation)
             off        = INIT / IDLE (outputs off)                            */
    {
      uint8_t  led_state = mon_sys_state;          /* single volatile read     */
      uint32_t now_ms    = HAL_GetTick();

      if (led_state == SYS_STATE_FAULT)
      {
        BSP_LED_On(LED_GREEN);
      }
      else if (led_state == SYS_STATE_SOFT_START)
      {
        if ((now_ms - led_last_toggle_ms) >= LED_BLINK_SOFTSTART_MS)
        {
          led_last_toggle_ms = now_ms;
          BSP_LED_Toggle(LED_GREEN);
        }
      }
      else if (led_state == SYS_STATE_RUN)
      {
        if ((now_ms - led_last_toggle_ms) >= LED_BLINK_RUN_MS)
        {
          led_last_toggle_ms = now_ms;
          BSP_LED_Toggle(LED_GREEN);
        }
      }
      else
      {
        BSP_LED_Off(LED_GREEN);
        led_last_toggle_ms = now_ms;   /* next blink starts a full period long */
      }
    }

    /* --- IWDG: refresh only while the 400 kHz control ISR is alive.
           If the ADC/DMA/trigger chain dies, the heartbeat stops advancing and
           the watchdog resets the MCU (2 s timeout).                          */
    {
      uint32_t count_now = mon_ctrl_loop_count;
      if (count_now != iwdg_last_ctrl_count)
      {
        iwdg_last_ctrl_count = count_now;
        (void)HAL_IWDG_Refresh(&hiwdg);
      }
    }
    /* USER CODE END WHILE */

    /* USER CODE BEGIN 3 */
  }
  /* USER CODE END 3 */
}

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
/* USER CODE BEGIN 4 */
/**
  * @brief  Clamp all CubeMonitor tunables to safe ranges (main-loop context).
  *         Also publishes the clamped duty ceiling for the control ISR so the
  *         ISR never reads an unclamped value.
  */
static void app_clamp_tunables(void)
{
  /* Pattern (TOCTOU-safe): read each volatile ONCE into a local, clamp the
     local with a NaN-rejecting comparison (!(v >= min) catches NaN as well as
     underrange), write the local back, and derive any cached value from the
     LOCAL — never from a re-read of the volatile.                            */
  float v;

  v = set_vout_V;
  if (!(v >= 0.0f))             { v = 0.0f; }
  else if (v > VOUT_SET_MAX_V)  { v = VOUT_SET_MAX_V; }
  set_vout_V = v;

  v = set_kp;
  if (!(v >= 0.0f))             { v = 0.0f; }
  set_kp = v;

  v = set_ki;
  if (!(v >= 0.0f))             { v = 0.0f; }
  set_ki = v;

  v = set_duty_max;
  if (!(v >= 0.0f))             { v = 0.0f; }
  else if (v > DUTY_MAX_ABS)    { v = DUTY_MAX_ABS; }
  set_duty_max = v;
  /* duty ceiling consumed by the control ISR: derived from the clamped local */
  ctrl_duty_max_cached = v;

  v = set_softstart_ms;
  if (!(v >= SOFTSTART_MS_MIN))  { v = SOFTSTART_MS_MIN; }
  else if (v > SOFTSTART_MS_MAX) { v = SOFTSTART_MS_MAX; }
  set_softstart_ms = v;

  v = set_oc_trip_A;
  if (!(v >= 0.0f))             { v = 0.0f; }
  else if (v > DAC_FULL_SCALE_A){ v = DAC_FULL_SCALE_A; }
  set_oc_trip_A = v;

  v = set_dt_ref_A;
  if (!(v >= 0.0f))             { v = 0.0f; }
  else if (v > DAC_FULL_SCALE_A){ v = DAC_FULL_SCALE_A; }
  set_dt_ref_A = v;
}

/**
  * @brief  Write the DAC comparator references when the requested trip levels
  *         change (main-loop context, never from an ISR).
  *         V_ref = I_trip * 0.25 V/A; DAC full scale = 3.3 V -> 13.2 A.
  */
static void app_apply_dac_refs(void)
{
  /* Each trip level is re-read from the volatile here, so it gets its own
     NaN-rejecting clamp: a NaN written between app_clamp_tunables() and this
     call must not reach the float->uint32 conversion (undefined for NaN).    */
  float trip;
  uint32_t counts;

  trip = set_oc_trip_A;
  if (!(trip >= 0.0f))              { trip = 0.0f; }
  else if (trip > DAC_FULL_SCALE_A) { trip = DAC_FULL_SCALE_A; }
  if (trip != dac_oc_applied_A)
  {
    counts = (uint32_t)(trip * AMPS_TO_DAC_COUNTS + 0.5f);
    if (counts > 4095u) { counts = 4095u; }
    (void)HAL_DAC_SetValue(&hdac1, DAC_CHANNEL_1, DAC_ALIGN_12B_R, counts); /* PROT_REF, PA4 */
    dac_oc_applied_A = trip;
  }

  trip = set_dt_ref_A;
  if (!(trip >= 0.0f))              { trip = 0.0f; }
  else if (trip > DAC_FULL_SCALE_A) { trip = DAC_FULL_SCALE_A; }
  if (trip != dac_dt_applied_A)
  {
    counts = (uint32_t)(trip * AMPS_TO_DAC_COUNTS + 0.5f);
    if (counts > 4095u) { counts = 4095u; }
    (void)HAL_DAC_SetValue(&hdac2, DAC_CHANNEL_1, DAC_ALIGN_12B_R, counts); /* DT_REF, PA6 */
    dac_dt_applied_A = trip;
  }
}
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

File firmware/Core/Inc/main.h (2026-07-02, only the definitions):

#define RCC_OSC32_IN_Pin GPIO_PIN_14
#define RCC_OSC32_IN_GPIO_Port GPIOC
#define RCC_OSC32_OUT_Pin GPIO_PIN_15
#define RCC_OSC32_OUT_GPIO_Port GPIOC
#define RCC_OSC_IN_Pin GPIO_PIN_0
#define RCC_OSC_IN_GPIO_Port GPIOF
#define RCC_OSC_OUT_Pin GPIO_PIN_1
#define RCC_OSC_OUT_GPIO_Port GPIOF
#define T_SWDIO_Pin GPIO_PIN_13
#define T_SWDIO_GPIO_Port GPIOA
#define T_SWCLK_Pin GPIO_PIN_14
#define T_SWCLK_GPIO_Port GPIOA
#define T_SWO_Pin GPIO_PIN_3
#define T_SWO_GPIO_Port GPIOB

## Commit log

2026-04-21 first setup
    [synch_buck_digital.kicad_pcb, synch_buck_digital.kicad_sch]
2026-04-21 *.bak *.bck *-backups/ .history/ *.kicad_pcb-bak *.kicad_sch-bak fabrication/ production/ jlcpcb/ gerbers/ bom/ pos/ *.zip .DS_Store Thumbs.db desktop.ini Please enter the commit message for your cha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
2026-04-22 pouring topology started
    [synch_buck_digital.kicad_pcb, synch_buck_digital.kicad_sch]
2026-04-22 Smaller SW Pour
    [synch_buck_digital.kicad_pcb]
2026-04-26 Updated pcb
    [synch_buck_digital.kicad_pcb]
2026-04-27 Updated pour topology
    [synch_buck_digital.kicad_pcb]
2026-04-28 Signal Traces Added
    [synch_buck_digital.kicad_pcb]
2026-04-28 More Traces
    [synch_buck_digital.kicad_pcb]
2026-04-28 Fixed FET Footprint and updated pour topology
    [synch_buck_digital.kicad_pcb]
2026-04-28 pcb finished
    [synch_buck_digital.kicad_pcb]
2026-04-28 Reduced board size
    [synch_buck_digital.kicad_pcb]
2026-04-29 Small Layout Change
    [synch_buck_digital.kicad_pcb]
2026-04-30 Small Changes
    [synch_buck_digital.kicad_pcb]
2026-05-12 Added stitching and thermal pours
    [synch_buck_digital.kicad_pcb, synch_buck_digital.kicad_sch]
2026-05-18 Small fix
    [Fet Stencil.kicad_pcb, Fet Stencil.kicad_sch, synch_buck_digital.kicad_pcb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]
2026-05-18 Small layout fix
    [synch_buck_digital.kicad_pcb]
2026-05-28 V1 finished. Final touchups to schematic planned
    [Fet Stencil.kicad_pcb, synch_buck_digital.kicad_pcb, synch_buck_digital.kicad_sch]
2026-06-01 Minor clean up
    [Fet Stencil.kicad_pcb, Fet Stencil.kicad_sch]
2026-06-01 fixed gitignore
    [bom.csv, designators.csv, positions.csv]
2026-07-02 Software developed, minor work needed to finish
    [synch_buck_digital.kicad_pcb]
2026-09-01 Fixed organization and structure
    [bom.csv, designators.csv, positions.csv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]
2026-09-01 Add project README and vendor 3D models into the repo
    [INA241A3IDDFR.step, Infineon_PG-TDSON-8.step, TLV3603DCKR.step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]
2026-09-01 Reposition schematic on sheet and add wiring
    [synch_buck_digital.kicad_sch]
2026-09-02 Fix 3D model orientation and add sense resistor model
    [synch_buck_digital.kicad_pcb]
2026-09-02 Add board renders, layer plots and schematic PDF
2026-09-02 Zoom out isometric render to fit the full board
2026-09-24 Reorganize .gitignore into grouped sections
    Same ignore patterns, regrouped by tool (KiCad, fabrication, firmware,
    IDEs, OS) with sub-headings and sorted entries.

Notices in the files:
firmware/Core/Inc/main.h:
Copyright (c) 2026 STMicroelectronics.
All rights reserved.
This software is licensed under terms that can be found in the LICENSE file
